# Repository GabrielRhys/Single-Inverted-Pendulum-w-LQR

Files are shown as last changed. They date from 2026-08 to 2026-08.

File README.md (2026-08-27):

Single Inverted Pendulum

Hardware assumptions:

These constants are specific to this rig, recalibrate them if you build your own:

1. CART_TRAVEL_METERS / CART_TRAVEL_COUNTS: physical rail length (0.40 m) and the raw encoder counts measured over that full travel (21028). Re-measure both for your rail and encoder.
2. PENDULUM_ZERO_RAW: the AS5600 raw reading with the pendulum hanging straight down. Read this value directly off your sensor at rest and swap it in.
3. K[4]: LQR gains [x, theta, x_dot, theta_dot], derived from this cart's mass, pendulum length/inertia, and motor force characteristics. These won't transfer to a different rig; re-derive from your own system model (or re-tune experimentally).
4. FORCE_TO_PWM / DEADBAND_PWM / MAX_PWM: map controller force output to motor PWM; depends on your motor/driver and supply voltage.
5. CART_SAFE_MARGIN: soft travel limit in encoder counts, set relative to wherever the cart is centered at power-on (no homing routine in this build).

Setup:
1. Center the cart by hand before powering on (position becomes the zero reference).
2. Hold the pendulum upright and still, it auto-arms within ARM_ANGLE/ARM_VEL of vertical.
3. Serial commands: k kill, space disarm, p print cart count, l start a 2000-sample angle log.

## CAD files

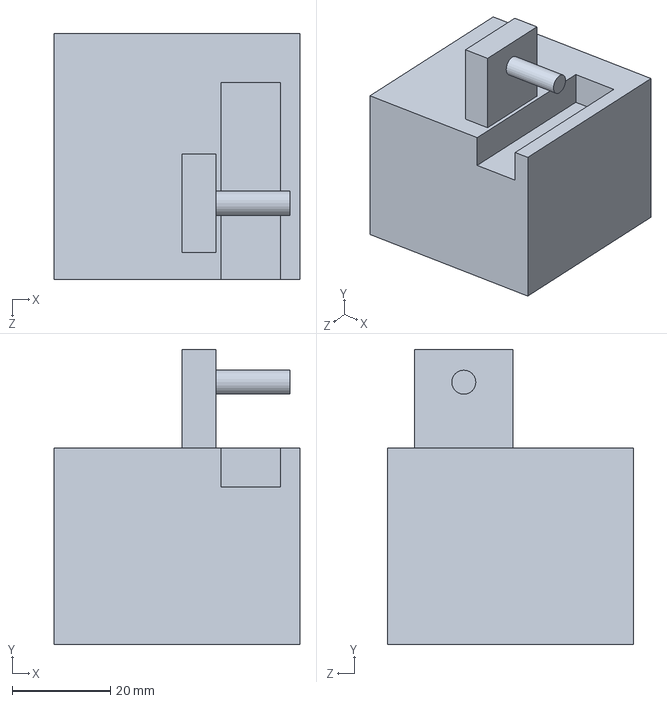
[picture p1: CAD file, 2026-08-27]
Parts and Assemblies/RIGHTSTAND.SLDPRT
50.0 x 60.0 x 50.0 mm

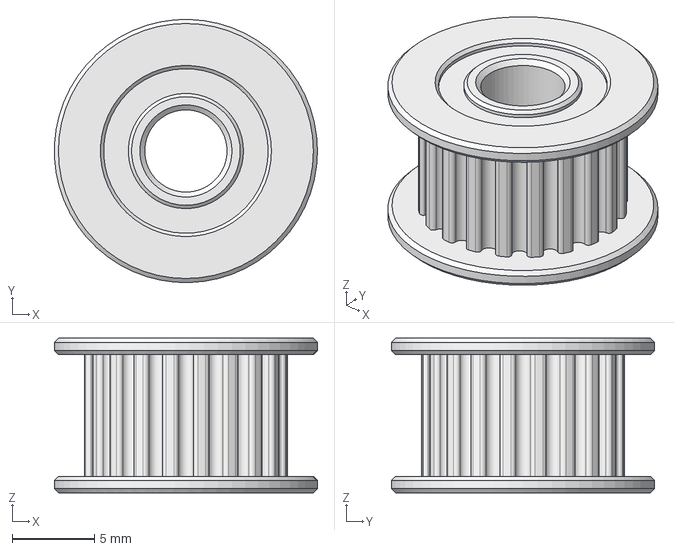
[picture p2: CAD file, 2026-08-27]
STL Files/GT2 Idler Pulley 20 Tooth 6mm Wide.step
16.0 x 16.0 x 9.40 mm

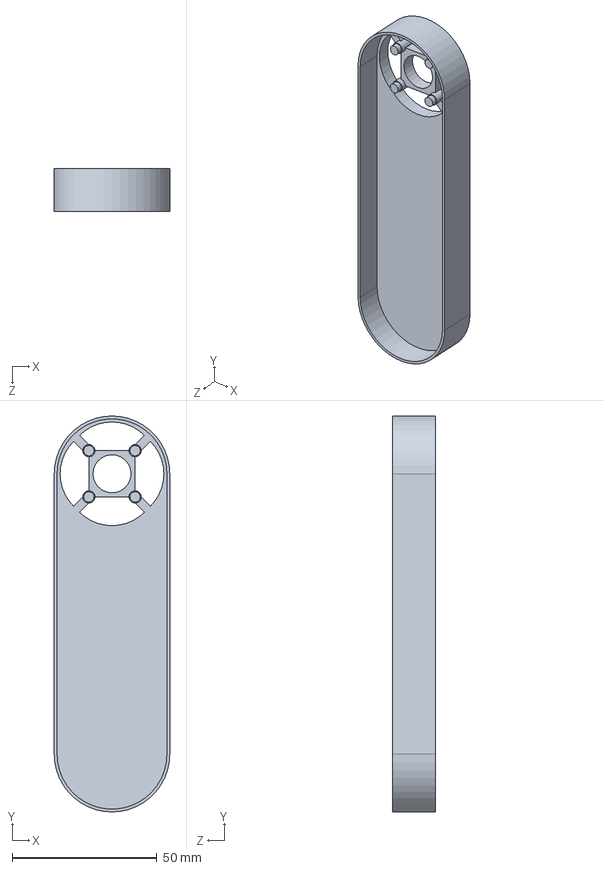
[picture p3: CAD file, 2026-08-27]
Parts and Assemblies/PENDULUM_2.SLDPRT
40.0 x 137.0 x 15.0 mm

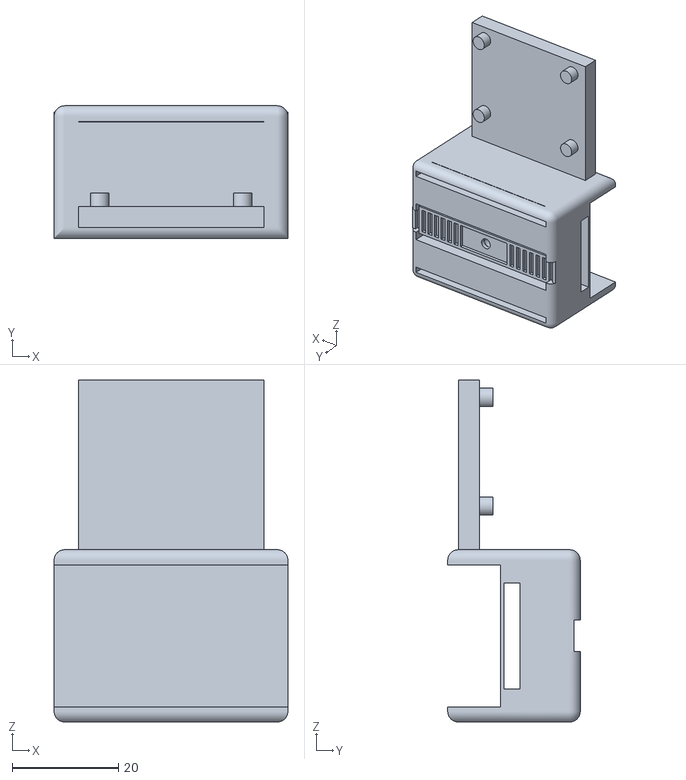
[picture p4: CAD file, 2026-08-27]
STL Files/CART_ATTACHMENT.STL
44.1 x 25.0 x 64.5

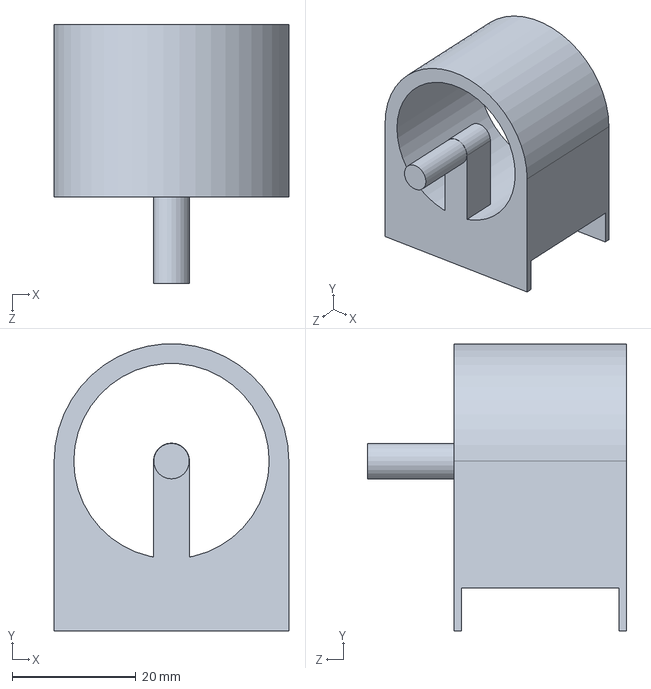
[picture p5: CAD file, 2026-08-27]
Parts and Assemblies/CART_WIRE_ROUTING_ATTACHMENT.SLDPRT
38.0 x 46.5 x 42.0 mm

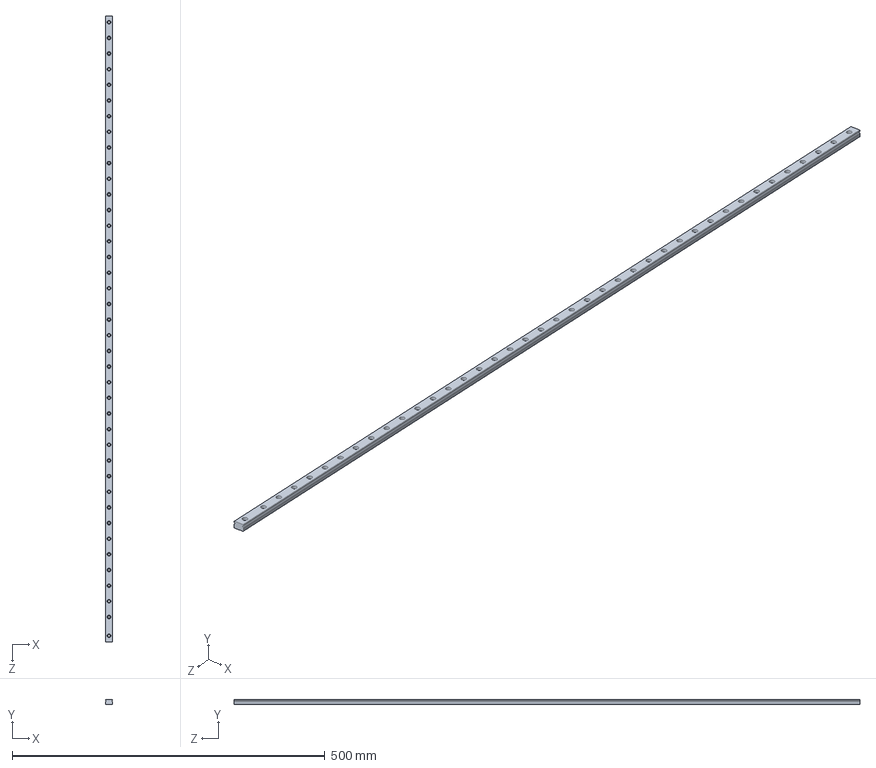
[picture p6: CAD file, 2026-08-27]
Parts and Assemblies/MGN12R CONFIGURABLE.SLDPRT
12.0 x 8.00 x 1000.0 mm

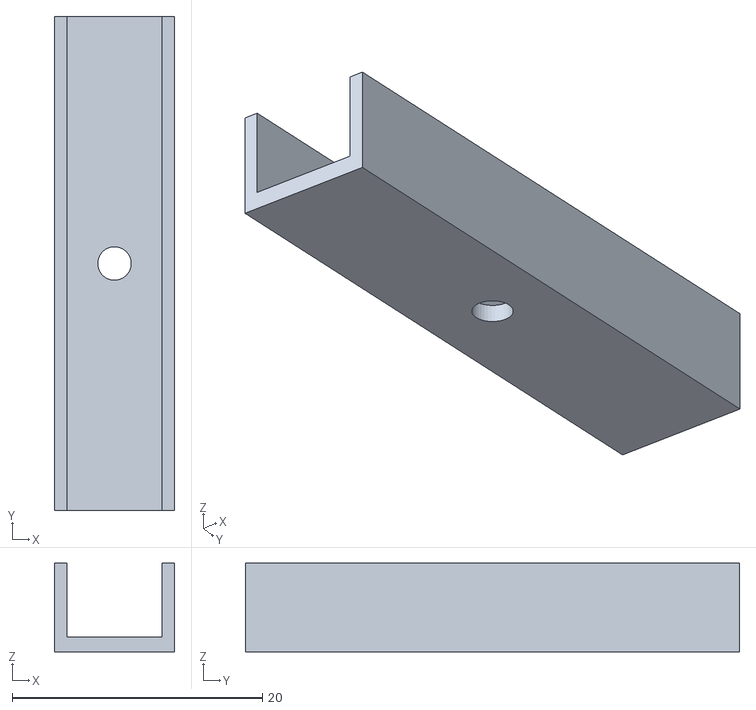
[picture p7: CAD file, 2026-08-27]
STL Files/GEARBELT_TOP_CLAMP.STL
9.60 x 39.5 x 7.09

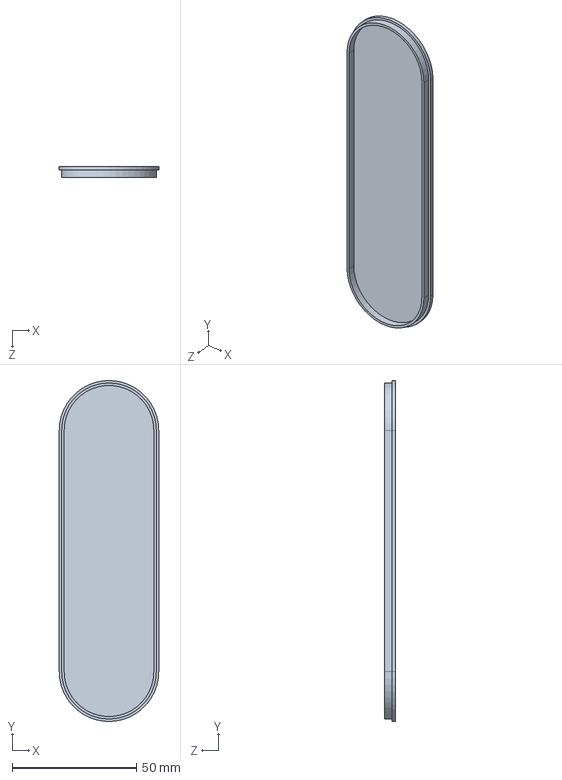
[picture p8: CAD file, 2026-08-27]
Parts and Assemblies/PENDULUM_2_LID.SLDPRT
40.0 x 137.0 x 4.50 mm

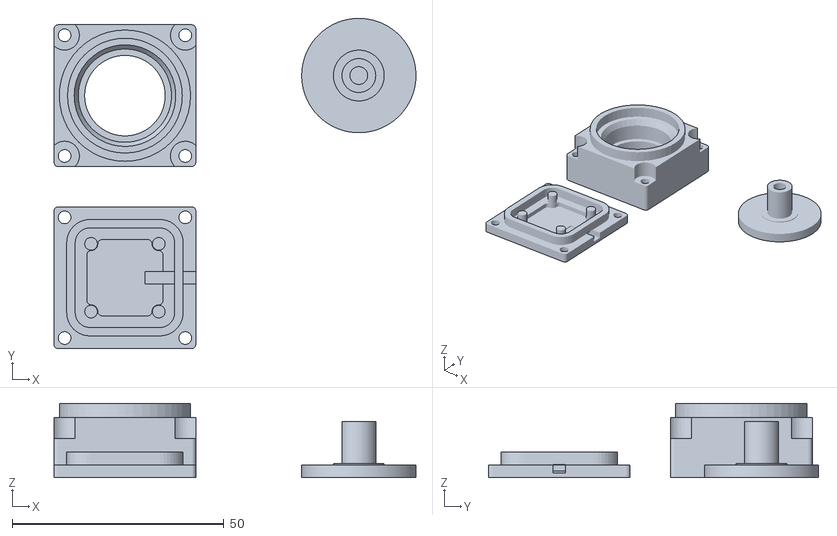
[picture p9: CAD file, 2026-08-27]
STL Files/as5600_mount.stl
85.5 x 78.0 x 17.5

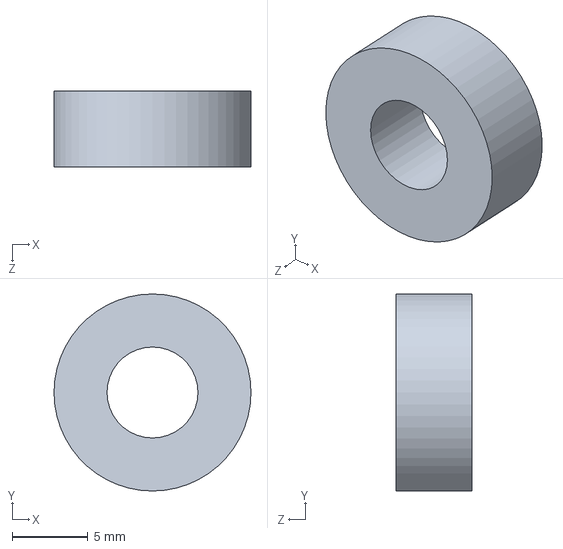
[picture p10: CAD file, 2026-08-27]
Parts and Assemblies/686-2RS_BEARING.SLDPRT
13.0 x 13.0 x 5.00 mm

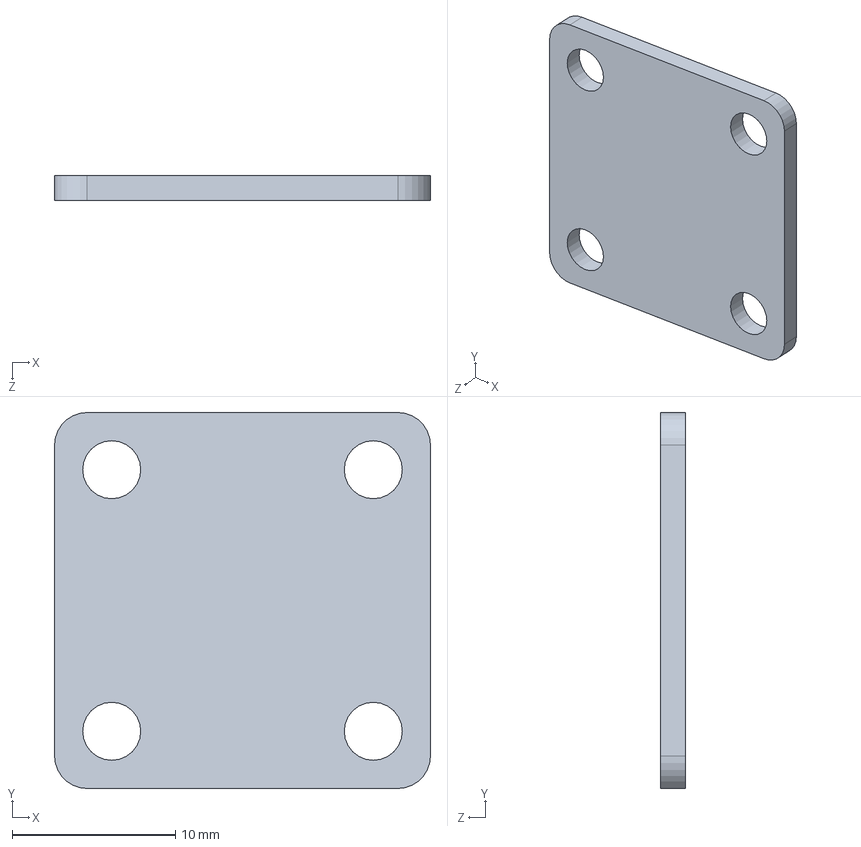
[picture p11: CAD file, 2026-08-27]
Parts and Assemblies/AS5600.SLDPRT
23.0 x 23.0 x 1.50 mm

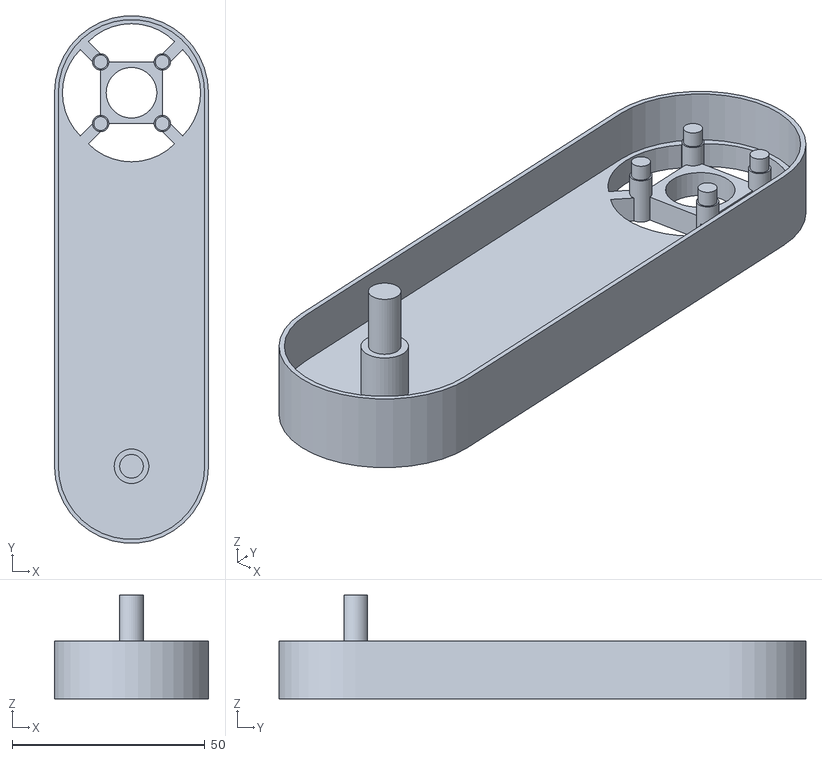
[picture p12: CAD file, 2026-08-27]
STL Files/PENDULUM_1.STL
40.0 x 136.9 x 27.0

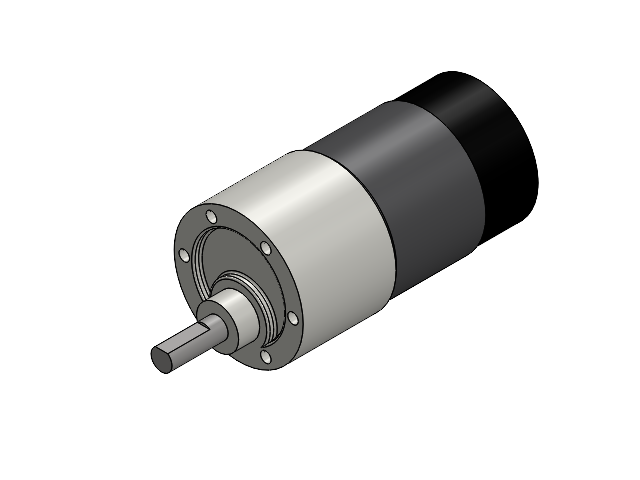
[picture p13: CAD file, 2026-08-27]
Parts and Assemblies/DCMOTORASSEMBLY.SLDASM
37D mm Metal Gearbox Polulu.stp
Motor DC 37D mm With 64 CPR Encoder.stp

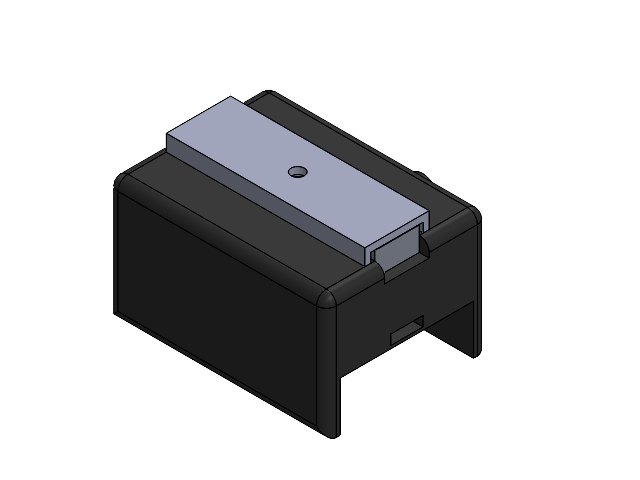
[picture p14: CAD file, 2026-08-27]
Parts and Assemblies/CART_ATTACHMENT.SLDASM
CART_ATTACHMENT
GT2 Aluminum Timing Belt Clamp
GEARBELT_TOP_CLAMP

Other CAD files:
Parts and Assemblies/Assem1.SLDASM
Parts and Assemblies/INVERTED_PENDULUM_ASSEMBLY.SLDASM
STL Files/CART_WIRE_ROUTING_ATTACHMENT.STL
STL Files/PENDULUM_2_LID.STL
Parts and Assemblies/Belt1-1.SLDPRT
Parts and Assemblies/CART_ATTACHMENT.3mf
Parts and Assemblies/CART_ATTACHMENT.SLDPRT
Parts and Assemblies/GEARBELT_TOP_CLAMP.3mf
Parts and Assemblies/GEARBELT_TOP_CLAMP.SLDPRT
Parts and Assemblies/GT2 Aluminum Timing Belt Clamp.SLDPRT
Parts and Assemblies/GT2 Aluminum Timing Belt Clamp.x_b
Parts and Assemblies/GT2 Idler Pulley.SLDPRT
Parts and Assemblies/GT2_20T.SLDPRT
Parts and Assemblies/IDLERPULLEYTESTROD.SLDPRT
Parts and Assemblies/LEFTSTAND.3mf
Parts and Assemblies/LEFTSTAND.SLDPRT
Parts and Assemblies/MAGNET.SLDPRT
Parts and Assemblies/MGN12H.SLDPRT
Parts and Assemblies/MOTORMOUNTINGBRACKET.SLDPRT
Parts and Assemblies/PENDULUM_1.3mf
Parts and Assemblies/PENDULUM_1.SLDPRT
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

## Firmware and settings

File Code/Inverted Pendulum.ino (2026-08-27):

/* Single Inverted Pendulum using an LQR controller
 *
 * Hardware:
 *   - Cart driven by a brushed DC motor through an BTS7960 H-bridge driver
 *   - Cart position from a quadrature encoder
 *   - Pendulum angle from an AS5600 magnetic encoder behind a TCA9548A I2C mux
 *
 * Control:
 *   - Full-state feedback (LQR gains K) on [x, theta, x_dot, theta_dot]
 *   - Runs on a fixed timestep via micros() in loop()
 *   - Auto-arms once the pendulum is held near upright and still
 *   - Auto-disarms (and cuts the motor) if the pendulum falls past FALL_LIMIT
 *
 * Serial commands:
 *   k -> kill / disarm
 *   space -> manual disarm
 *   p -> print current cart encoder count
 *   l -> start a fixed-length angle log, dumped to Serial when full
 */

#include <Wire.h>

// I2C / angle sensor
#define MUX_ADDR 0x70   // TCA9548A I2C multiplexer
#define AS5600_ADDR 0x36
#define AS5600_ANGLE_H 0x0E   // raw angle, high byte

const int PENDULUM_MUX_CHANNEL = 2;      // mux channel the pendulum's AS5600 is on
const int PENDULUM_ZERO_RAW    = 258;    // raw AS5600 count corresponding to "hanging down"
const float PENDULUM_SIGN        = 1.0;    // flip if angle increases the wrong way

// Motor driver (IBT-2 style H-bridge) + cart encoder
const int RPWM = 25, LPWM = 26, R_EN = 27, L_EN = 14;
const int ENC_A = 18, ENC_B = 19;

volatile long cartCount = 0;

// Cart geometry / unit conversion
const float CART_SIGN            = -1.0;               // flip if +x is the wrong direction
const float CART_TRAVEL_METERS   = 0.40;                // full rail travel
const float CART_TRAVEL_COUNTS   = 21028.0;              // encoder counts over that travel
const float METERS_PER_COUNT     = CART_TRAVEL_METERS / CART_TRAVEL_COUNTS;
const float RAD_PER_COUNT        = (2.0 * PI) / 4096.0;   // AS5600 is a 12-bit sensor (4096 counts/rev)

// Soft travel limits (set relative to power-on position)
long CART_MIN_COUNT, CART_MAX_COUNT;
const long  CART_SAFE_MARGIN = 8000;

// Arming / safety thresholds
const float ARM_ANGLE  = 0.10;  // rad — must be within this of upright to auto-arm
const float ARM_VEL    = 0.5;   // rad/s — must be this slow to auto-arm
const float FALL_LIMIT = 0.6;   // rad — auto-disarm past this

// LQR gains: force = -(K0*x + K1*theta + K2*x_dot + K3*theta_dot)
const float K[4] = {-6, -9.0507, -10, -1.2490}; // [x, theta, x_dot, theta_dot]

// Force -> PWM mapping
const int MAX_PWM      = 230;
const int DEADBAND_PWM = 50;    // minimum PWM needed to actually move the cart
const float FORCE_EPS    = 0.01;  // below this, just stop rather than dither
const float FORCE_TO_PWM = 150.0;

// Control loop timing
const unsigned long CONTROL_PERIOD_US = 4000; // 250 Hz control loop

// Velocity estimation (windowed finite difference on x and theta)
const int VEL_WINDOW = 7;
float xBuf[VEL_WINDOW], thBuf[VEL_WINDOW], tBuf[VEL_WINDOW];
int velIdx = 0;
bool velBufFull = false;

// Angle logger (for tuning / plotting)
#define LOG_SIZE 2000
float logBuf[LOG_SIZE];
unsigned long logTime[LOG_SIZE];
int logIndex = 0;
bool logging = false;

// State
bool  armed = false;
float x, theta;
float dx = 0, dtheta = 0;
float x_prev = 0, theta_prev = 0;
unsigned long t_prev_ctrl;

// Diagnostics reported once per second
unsigned long loopCounter = 0, lastRateReport = 0;
float measuredHz = 0;
unsigned long badReads = 0, muxFails = 0;

// Encoder ISR
void IRAM_ATTR handleCartEncoderA() {
  if (digitalRead(ENC_A) == digitalRead(ENC_B)) cartCount++;
  else cartCount--;
}

// Motor helpers
void stopMotor() {
  analogWrite(RPWM, 0);
  analogWrite(LPWM, 0);
}

// Push the cart with a signed force, respecting soft limits and deadband.
void applyForce(float force) {
  if (cartCount <= CART_MIN_COUNT && force > 0) { stopMotor(); return; }
  if (cartCount >= CART_MAX_COUNT && force < 0) { stopMotor(); return; }
  if (fabs(force) < FORCE_EPS) { stopMotor(); return; }

  int pwm = DEADBAND_PWM + (int)(fabs(force) * FORCE_TO_PWM);
  if (pwm > MAX_PWM) pwm = MAX_PWM;

  if (force > 0) { analogWrite(LPWM, 0);   analogWrite(RPWM, pwm); }
  else { analogWrite(RPWM, 0);   analogWrite(LPWM, pwm); }
}

// AS5600 helpers
bool muxSelect(uint8_t channel) {
  Wire.beginTransmission(MUX_ADDR);
  Wire.write(1 << channel);
  uint8_t result = Wire.endTransmission();
  if (result != 0) { muxFails++; return false; }
  return true;
}

uint16_t readRawAngle() {
  Wire.beginTransmission(AS5600_ADDR);
  Wire.write(AS5600_ANGLE_H);
  Wire.endTransmission(false);
  Wire.requestFrom(AS5600_ADDR, 2);
  if (Wire.available() < 2) return 0xFFFF; // sentinel: read failed
  uint16_t hi = Wire.read(), lo = Wire.read();
  return ((hi << 8) | lo) & 0x0FFF;
}

// Convert a raw AS5600 count to a signed angle in (-pi, pi], relative to zeroRaw.
float rawToAngle(uint16_t raw, int zeroRaw, float sign) {
  float a = (float)(raw - zeroRaw) * RAD_PER_COUNT + PI;
  while (a > PI)  a -= 2 * PI;
  while (a < -PI) a += 2 * PI;
  return sign * a;
}

// Control loop — called once per CONTROL_PERIOD_US (4000/250Hz)
void controlStep(float dt) {
  // Read state
  x = CART_SIGN * (float)cartCount * METERS_PER_COUNT;

  bool pendulumOk = muxSelect(PENDULUM_MUX_CHANNEL);
  uint16_t raw = pendulumOk ? readRawAngle() : 0xFFFF;
  if (raw == 0xFFFF) badReads++;
  else theta = rawToAngle(raw, PENDULUM_ZERO_RAW, PENDULUM_SIGN);

  //  Estimate velocities over a sliding window
  static float tAccum = 0;
  tAccum += dt;
  xBuf[velIdx]  = x;
  thBuf[velIdx] = theta;
  tBuf[velIdx]  = tAccum;
  int newest = velIdx;
  velIdx = (velIdx + 1) % VEL_WINDOW;
  if (velIdx == 0) velBufFull = true;

  if (velBufFull) {
    int oldest = velIdx;
    float windowDt = tBuf[newest] - tBuf[oldest];
    if (windowDt > 1e-4) {
      dx     = (xBuf[newest]  - xBuf[oldest])  / windowDt;
      dtheta = (thBuf[newest] - thBuf[oldest]) / windowDt;
    }
  } else {
    // Not enough samples yet
    dx     = (x     - x_prev)     / dt;
    dtheta = (theta - theta_prev) / dt;
  }
  x_prev = x;
  theta_prev = theta;

  //Disarm on fall
  if (armed && fabs(theta) > FALL_LIMIT) {
    armed = false;
    stopMotor();
    Serial.println("FELL - disarmed");
    return;
  }

  // --- LQR control ---
  if (armed) {
    float force = -(K[0] * x + K[1] * theta + K[2] * dx + K[3] * dtheta);
    applyForce(force);
  } else {
    stopMotor();
  }
}

// Logging
void dumpLog() {
  Serial.println("---LOG START---");
  for (int i = 0; i < logIndex; i++) {
    Serial.print(logTime[i]);
    Serial.print(",");
    Serial.println(logBuf[i], 4);
  }
  Serial.println("---LOG END---");
}

// Serial command handling
void handleSerialCommands() {
  if (!Serial.available()) return;

  char c = Serial.read();
  switch (c) {
    case 'k':
      armed = false;
      stopMotor();
      Serial.println("KILLED");
      break;
    case ' ':
      armed = false;
      stopMotor();
      Serial.println("manual disarm");
      break;
    case 'p':
      Serial.print("cartCount = ");
      Serial.println(cartCount);
      break;
    case 'l':
      logIndex = 0;
      logging = true;
      Serial.println("LOGGING STARTED");
      break;
  }
}

// Setup / loop
void setup() {
  Serial.begin(115200);
  Wire.begin();
  Wire.setClock(100000);

  pinMode(R_EN, OUTPUT);
  pinMode(L_EN, OUTPUT);
  digitalWrite(R_EN, HIGH);
  digitalWrite(L_EN, HIGH);
  stopMotor();

  pinMode(ENC_A, INPUT_PULLUP);
  pinMode(ENC_B, INPUT_PULLUP);
  attachInterrupt(digitalPinToInterrupt(ENC_A), handleCartEncoderA, CHANGE);
  delay(500);

  // NOTE: this build skips automatic homing —> center the cart by hand
  // before power-on, and treat that position as the zero reference.
  Serial.println("Manual mode: no homing. Center the cart by hand before powering on.");
  cartCount = 0;
  CART_MIN_COUNT = cartCount - CART_SAFE_MARGIN;
  CART_MAX_COUNT = cartCount + CART_SAFE_MARGIN;
  Serial.print("Soft limits set: ");
  Serial.print(CART_MIN_COUNT);
  Serial.print(" to ");
  Serial.println(CART_MAX_COUNT);
  delay(500);

  t_prev_ctrl = micros();
  lastRateReport = millis();
  Serial.println("Hold pendulum UP. Space=ARM, k=KILL.");
}

void loop() {
  handleSerialCommands();

  unsigned long now = micros();
  if (now - t_prev_ctrl >= CONTROL_PERIOD_US) {
    float dt = (now - t_prev_ctrl) * 1e-6;
    t_prev_ctrl = now;
    controlStep(dt);
    loopCounter++;

    if (!armed && fabs(theta) < ARM_ANGLE && fabs(dtheta) < ARM_VEL) {
      armed = true;
      Serial.println(">>> AUTO-ARMED <<<");
    }

    if (logging && logIndex < LOG_SIZE) {
      logTime[logIndex] = now;
      logBuf[logIndex]  = theta;
      logIndex++;
    } else if (logging && logIndex >= LOG_SIZE) {
      logging = false;
      dumpLog();
    }
  }

  // Once-per-second diagnostics
  if (millis() - lastRateReport >= 1000) {
    measuredHz = loopCounter;
    loopCounter = 0;
    lastRateReport = millis();

    Serial.print("rate=");     Serial.print(measuredHz, 0);
    Serial.print(" theta=");   Serial.print(theta, 2);
    Serial.print(" badReads="); Serial.print(badReads);
    Serial.print(" muxFails="); Serial.print(muxFails);
    Serial.println(armed ? " [ARM]" : " [off]");
  }
}
